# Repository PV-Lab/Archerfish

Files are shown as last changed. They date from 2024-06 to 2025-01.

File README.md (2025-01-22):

# \#Archerfish

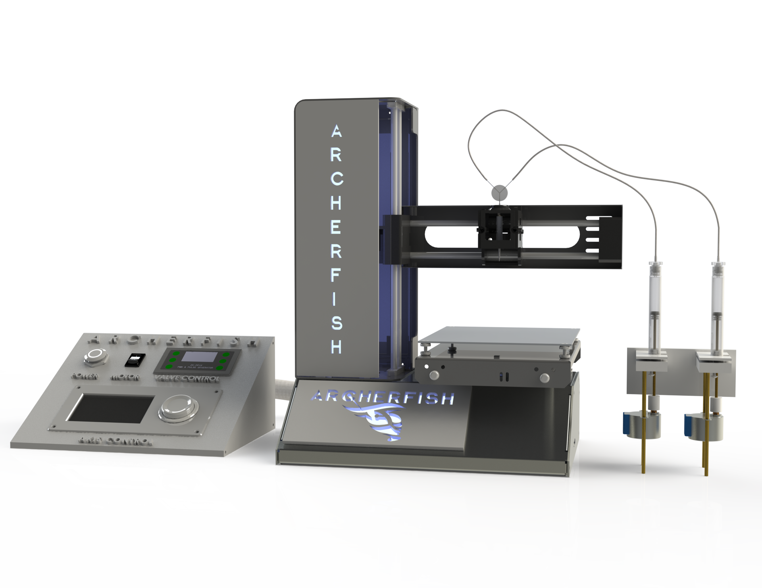
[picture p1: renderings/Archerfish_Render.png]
Archerfish


**Project Name:** \#Archerfish

**Project Lead:** Aleks Siemenn \<<asiemenn@mit.edu>\>

**Collaborators:** Jim Serdy, Basita Das, Eunice Aissi, Tonio Buonassisi

**Abstract**: The principle of "build fast, fail faster" has significantly shortened the timeline from ideation to final product in mechanical engineering, paralleling the rise of 3D printing technology and rapid prototyping. In contrast, material science has yet to achieve similar advancements in rapid learning cycles, hindered by the predominantly manual nature of its experimental procedures. For example, to test a material, it is conventionally synthesized at the same fidelity as industry standards, such as using manual spin coating, rather than being treated as a "rapid prototype." Implementing rapid prototyping principles into parts of these experimental procedures can help to shorten the timeline of the materials development pipeline, just as it does for mechanical design. Here, we introduce the design of Archerfish, a low-cost and high-throughput combinatorial mixing and deposition platform to accelerate the screening of material compounds. With this high-throughput combinatorial printing (HTCP) design, we demonstrate combinatorial mixing and printing throughputs of 250 unique compounds per minute. Furthermore, we validate the formation of combinatorial material gradients using hyperspectral image analysis. The proposed low-cost HTCP design expands accessibility to rapid materials screening technology, enabling scientists to make faster experimentally-informed decisions for the development of new materials. 

## Explanation of code within GitHub Repo:
### [1] Archerfish BOM.xlxs
Detailed Bill of Materials for the Archerfish System. 

### [2] /Code/Microcontroller Syringe Pump Code/Microcontroller-Syringe-Pump-Code.ino
Simple Arduino Mega gradient printing code for two 28BYJ-48 5V Stepper Motors with ULN2003 Drivers. This code drives both syringes in the archerfish system to create a gradient of droplets. Package version AccelStepper >= 1.64 and Arudino IDE >= 2.2.1 were used to develop this code.

### [3] /Code/Printer G-code/Raster Pattern.gcode
G-code for a Monoprice MP Select Mini 3D Printer to raster the gradient printed by the Archerfish system on a 100mm x 100mm polyester sheet. Marlin-flavor G-code is used to develop this code.

### [4] /Code/Script to Update G-code/Update_gcode.ipynb
Python notebook script to update an existing g-code file to the dimensions of any 3D printer bed size.

### [5] /CAD/Full Archerfish System Assembly.zip
Detailed CAD Model of the Archerfish System. Open-access CAD model of the complete Archerfish assembly can also be found on [GrabCAD](https://grabcad.com/library/archerfish-1). Included in this folder are the Solidworks files and 3D-printable STL files for all custom components.

### [6] /CAD/Droplet Generator and Junction
Contains all Solidworks part files and 3D-printable STL files to reproduce the droplet generation and junction assembly.

### [7] /CAD/Syringe Pump
Contains all Solidworks part files and 3D-printable STL files to reproduce the syringe pump holder assembly.

### [8] /data
The folder contains the paper's relevant hyperspectral, EDS, and profilometry data.

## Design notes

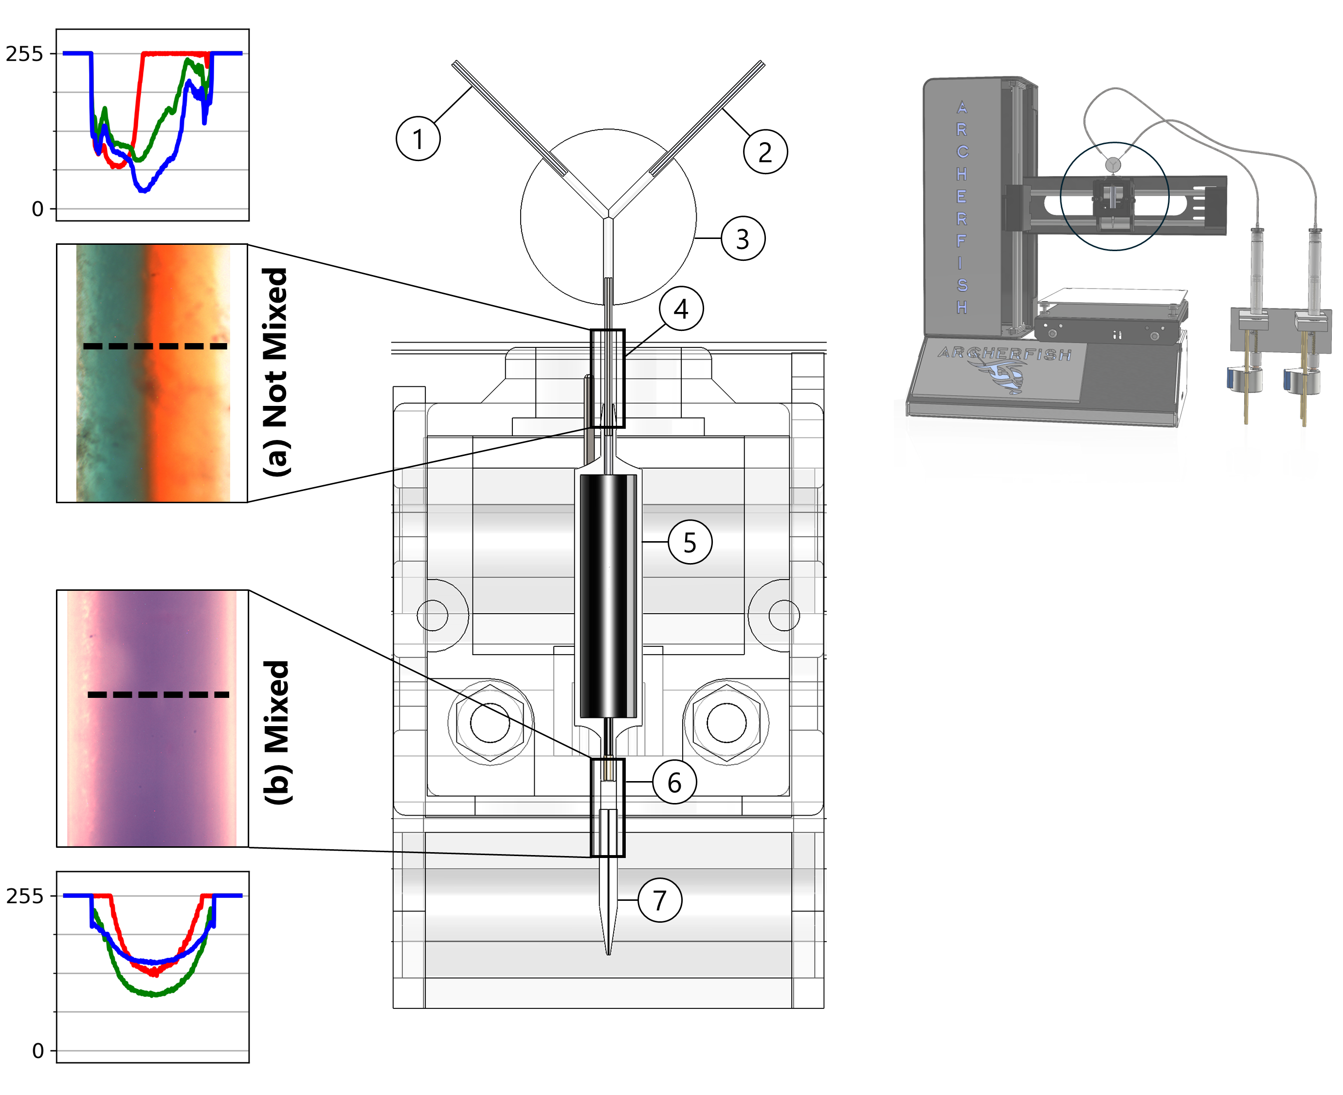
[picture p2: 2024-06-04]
renderings/Junction_nozzle_mixing_R1.png

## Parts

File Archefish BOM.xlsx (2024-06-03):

Summary Table
General Description | Cost
Lee Valve | $183.58
Mono Price Printer | $175.99
Nozzle | $50.00
Arduino Mega | $48.90
Fittings, Tubing, and Pumps | $23.39
PWM Driver | $10.57
Buttons & Switch | $8.82
Motors | $5.90
Total | $507.15
Sub-Assembly refers to the labels in Archerfish_render_complete_R2.png
Sub-Assembly | Image in Github Repo | Label in Figure | Item Name | Description | Vendor | Part Number | Qty | Cost/Item | Cost/Item | Link to Where to Purchase
1 | Archerfish_UI_Box.png | 1 | Screen and Control | Axis Controls From Monoprice 3D Printer | Mono Price
 |  | 2 | Power | Power Button | Digikey | SW-PB7-1Z-A-LRRG-H-3-G2A | 1 | $7.56 | $7.56 | https://www.digikey.com/en/products/detail/adam-tech/SW-PB7-1Z-A-LRRG-H-3-G2A/15284462?gad_source=1
 |  | 3 | UI Box | User Interface Box (PLA) | 3D printed |  | 1 | $0.00 | $0.00 | CAD File:
 |  | 4 | Switch | Motor Switch | Digikey | RF1-1A-DC-2-R-1 | 1 | $1.26 | $1.26 | https://www.digikey.com/en/products/detail/triad-components-group,-inc/RF1-1A-DC-2-R-1/11492837?gad_source=1
 |  | 5 | PWM Driver | ZK-PP2K 24V High Power PWM Driver | Amazon |  | 1 | $10.57 | $10.57 | https://www.amazon.com/ZK-PP2K-dimming-regulating-frequency-adjustable/dp/B0C7H1QFR8
2 | Archerfish_render_complete_R2.png | 2 | 3D Printer | Monoprice MP Select Mini 3D Printer (discontinued) | Mono Price |  | 1 | $175.99 | $175.99 | https://www.amazon.com/Monoprice-Select-Mini-Printer-Assembled/dp/B073ZLSMFT
3 | Junction_nozzle_mixing_R2.png | 1 & 2 | Metal Inlets | 0.55 mm ID x 0.65 mm OD x 25 mm, 304 stainless steel | McMaster-Carr | 5560K63 | 3 | $0.65 | $1.96 | https://www.mcmaster.com/5560K63-5560K332/
 |  | 3 | Junction | Fluid Junction. From 0.25" thick polyoxymethylene (POM/Acetal) disk with three 0.6 mm holes drilled 90 degrees apart | McMaster-Carr | 8497K311 | 1 | $6.26 | $6.26 | https://www.mcmaster.com/8497K311/
 |  | 4 & 6 |  | 0.5 mm ID x 2 mm OD silicone Tubing | Amazon |  | 2 | $0.03 | $0.06 | https://www.amazon.com/Hooshing-Silicone-Flexible-Winemaking-Transfer/dp/B0BJ1XCKGK?th=1
 |  | 5 | Valve | In-line Piezoelectric Valve | Lee Valves | INKA2424212H VHS Series P-P | 1 | $183.58 | $183.58 | https://www.theleeco.com/product/vhs-series-2-way-dispense-solenoid-valve/
 |  | 7 | Nozzle | 300 um Diameter Flow-focusing micro-nozzle outlet | Small Precision Tools | 1551-120-437P 200 (10-11D-20) | 1 | $50.00 | $50.00 | https://www.smallprecisiontools.com/en/homepage/?oid=55&lang=en
4 | Syringe_pump_construction_R2.png | 1 | Lines | Fluid Lines 1 mm ID and 2 mm OD PTFE [3 ft] | McMaster-Carr | 7130N273 | 2 | $4.38 | $8.76 | https://www.mcmaster.com/7130N273/
 |  | 2 | Luer lock | Barbed luer lock (1.5 mm, polypropylene (PP)) | McMaster-Carr | 51525K291 | 2 | $0.62 | $1.24 | https://www.mcmaster.com/51525K291/
 |  | 3 | Syringe | Syringe holding volume for precursor solutions (3 mL with luer lock connection, PP) | McMaster-Carr | 7510A42 | 2 | $1.22 | $2.44 | https://www.mcmaster.com/7510A42/
 |  | 4 | Plunger | Syringe plunger cap (silicone) | Sub-Unit of a Syringe. Made in-house. |  | 2 |  | $0.00
 |  | 5 | Shaft | Threaded plunger shaft (#4-40 threads × 75 mm length, 18-8 stainless steel), | McMaster-Carr | 95412A410 | 2 | $1.14 | $2.28 | https://www.mcmaster.com/95412A410/
 |  | 6 | Plunger Coupling | Plunger shaft coupling to convert angular to linear velocity (#4-40 threads, polyoxymethylene (POM), 3/8" Rod 5/16" long) | McMaster-Carr | 8497K171 | 1 | $0.03 | $0.03 | https://www.mcmaster.com/8497K171/
 |  | 7 | Rails | Stepper motor rails (3 mm diameter × 90 mm length, aluminum) | McMaster-Carr | 8974K19 | 1 | $0.31 | $0.31 | https://www.mcmaster.com/8974K19/
 |  | 8 | Motor Coupling | Motor shaft coupling with lead screw (POM, 3/8" Rod 1/2" Long ) | McMaster-Carr | 8497K171 | 1 | $0.05 | $0.05 | https://www.mcmaster.com/8497K171/
 |  | 9 | Motors | 28BYJ-48 5V Stepper Motors + ULN2003 Driver | Amazon |  | 2 | $2.95 | $5.90 | https://www.amazon.com/Stepper-28BYJ-48-ULN2003-Arduino-Electric/dp/B07V5V2FZX?hvadid=693270340266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
 |  | Not Depicted | Mega | Arduino Mega | Amazon |  | 1 | $48.90 | $48.90 | https://www.amazon.com/ARDUINO-MEGA-2560-REV3-A000067/dp/B0046AMGW0?hvadid=693392565994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
 |  |  |  |  |  |  | Total |  | $507.15

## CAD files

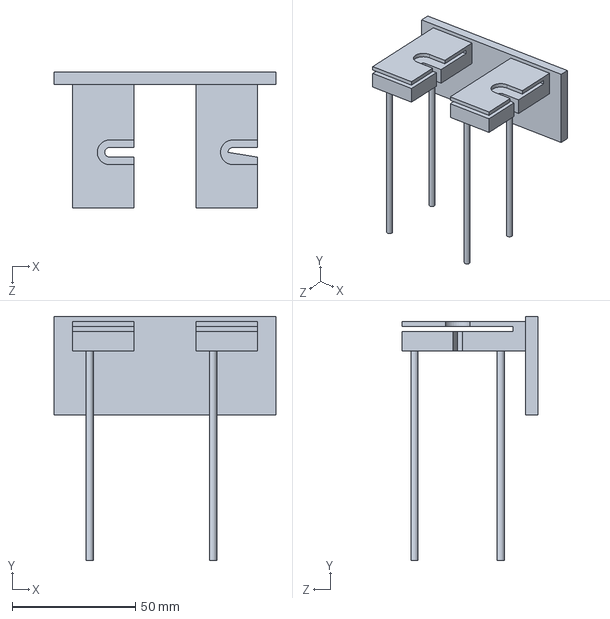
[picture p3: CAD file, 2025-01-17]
CAD/Syringe Pump/Solidworks Files/Full Syringe Holder.SLDPRT
90.0 x 99.0 x 55.0 mm

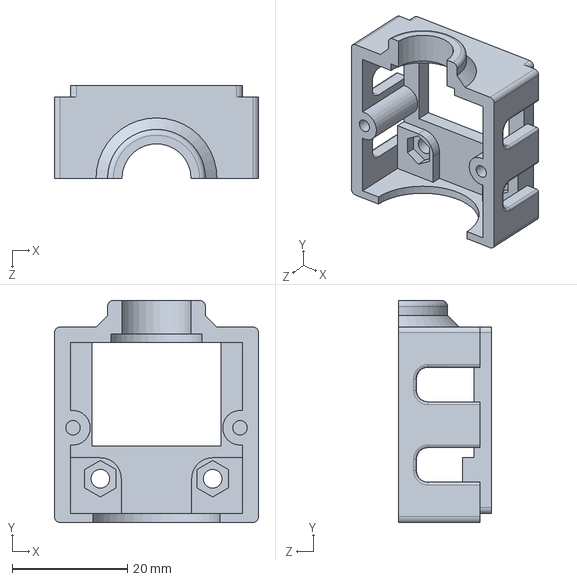
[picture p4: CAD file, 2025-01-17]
CAD/Droplet Generator and Junction/Solidworks Files/Droplet Generator Back Cover.SLDPRT
35.5 x 38.5 x 16.1 mm

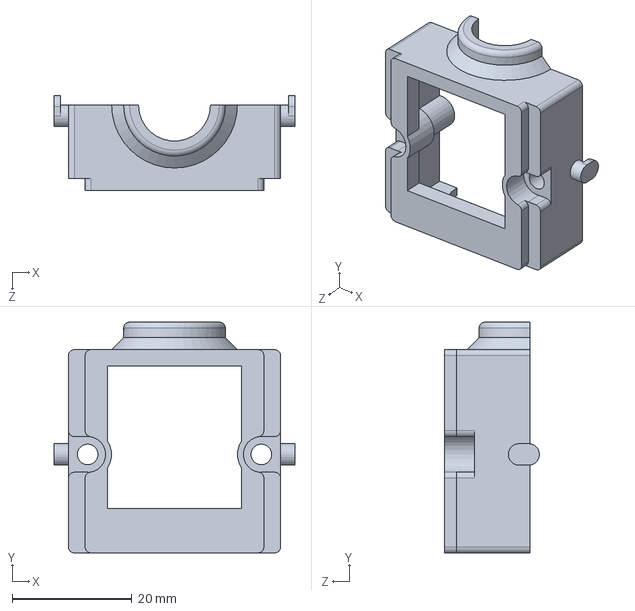
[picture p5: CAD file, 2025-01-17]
CAD/Droplet Generator and Junction/Solidworks Files/Droplet Generator Front Cover.SLDPRT
40.2 x 38.5 x 15.9 mm

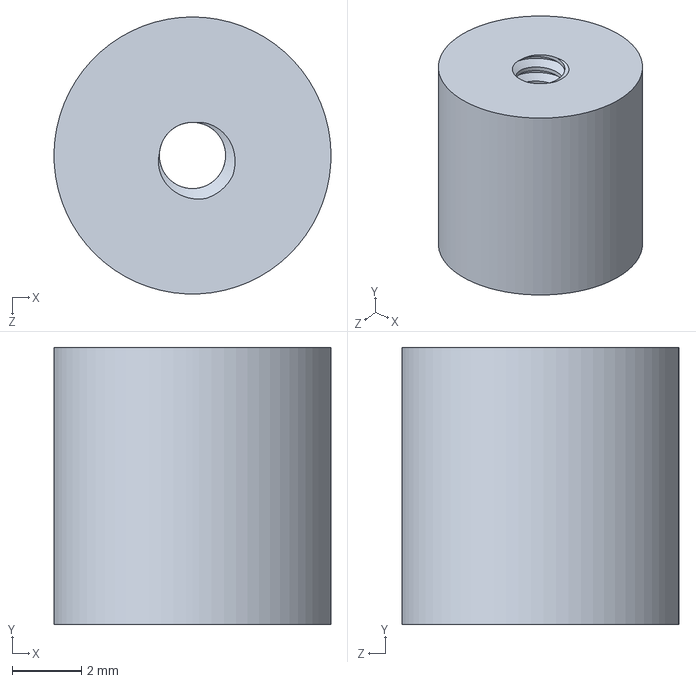
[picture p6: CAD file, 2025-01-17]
CAD/Syringe Pump/Solidworks Files/Syringe Pump Drive-to-Syringe Coupling.SLDPRT
8.00 x 8.00 x 8.00 mm

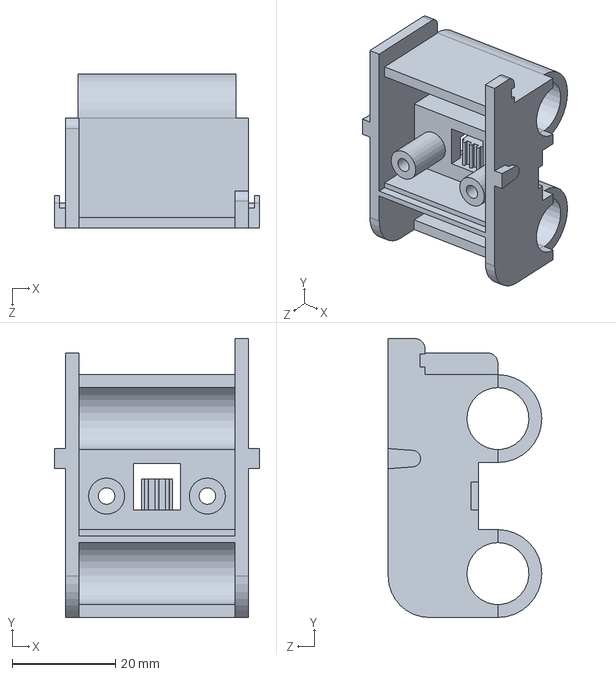
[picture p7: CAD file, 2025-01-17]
CAD/Droplet Generator and Junction/Solidworks Files/Droplet Generator Mount.SLDPRT
39.7 x 54.0 x 29.8 mm

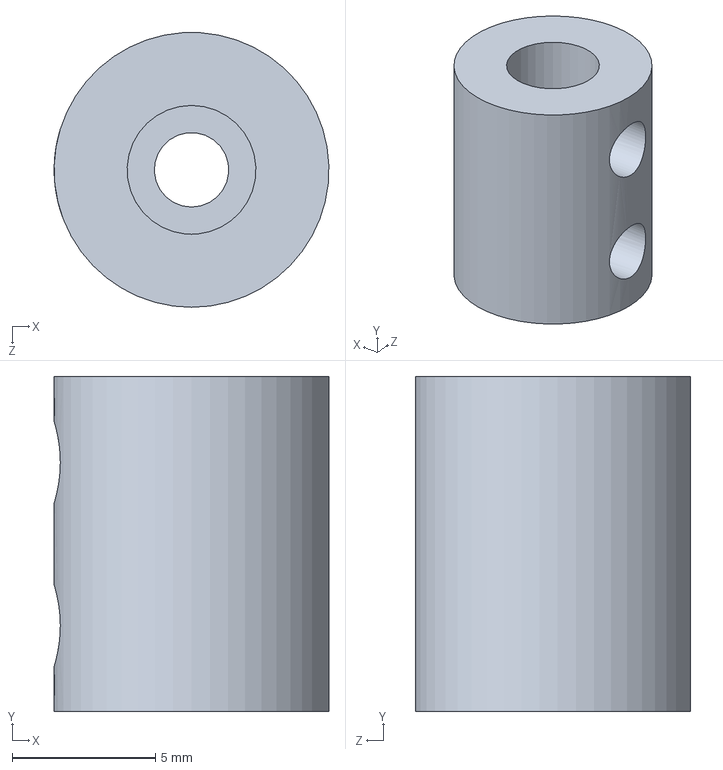
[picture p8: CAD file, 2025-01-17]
CAD/Syringe Pump/Solidworks Files/Syringe Pump Drive-to-Motor Coupling.SLDPRT
9.60 x 11.7 x 9.59 mm

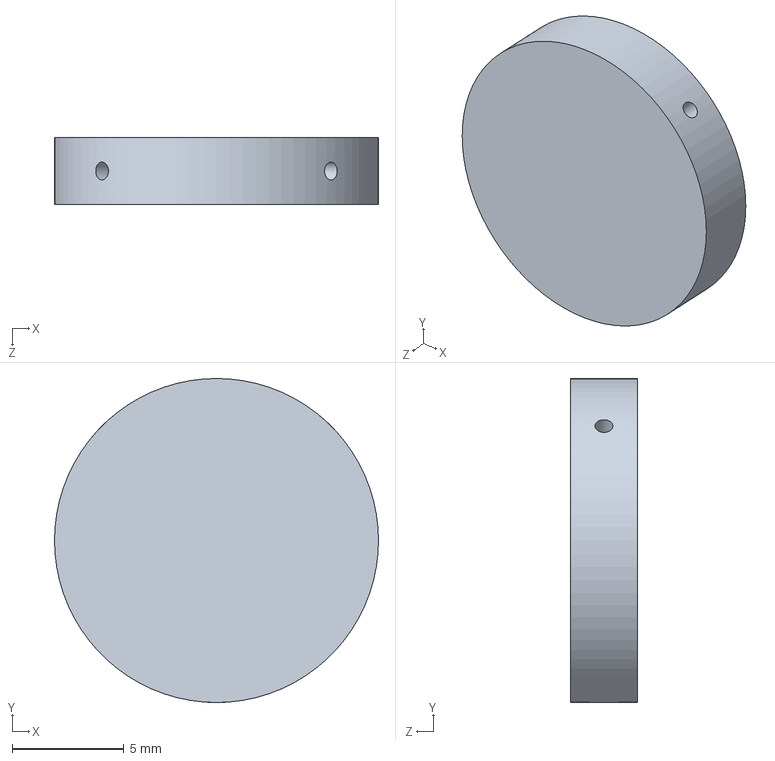
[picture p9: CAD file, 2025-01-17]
CAD/Droplet Generator and Junction/Solidworks Files/Junction Mixer 45 Degrees.SLDPRT
14.5 x 14.5 x 3.00 mm

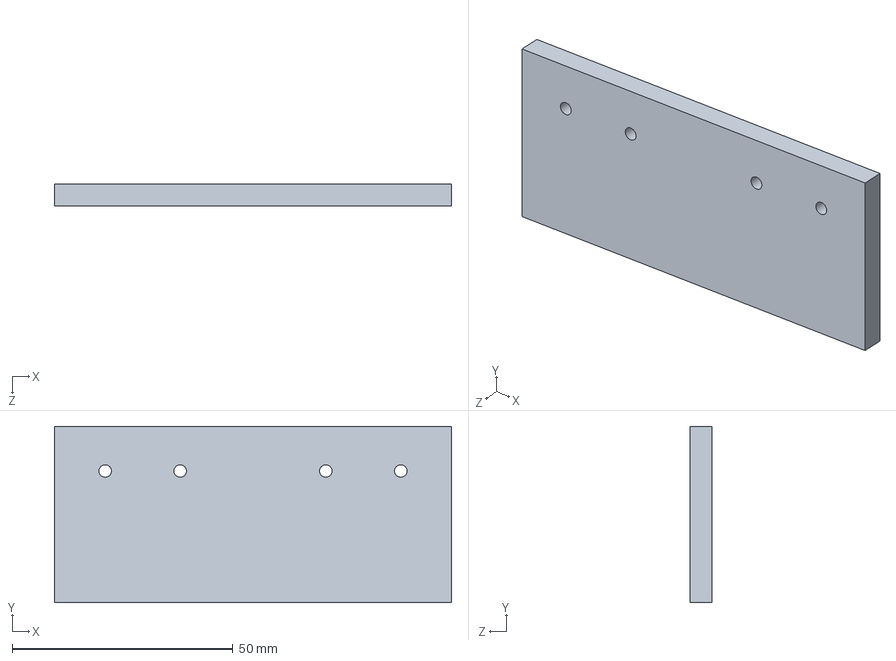
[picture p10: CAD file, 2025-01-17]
CAD/Syringe Pump/Solidworks Files/Syringe Holder Back Plate.SLDPRT
90.0 x 40.0 x 5.00 mm

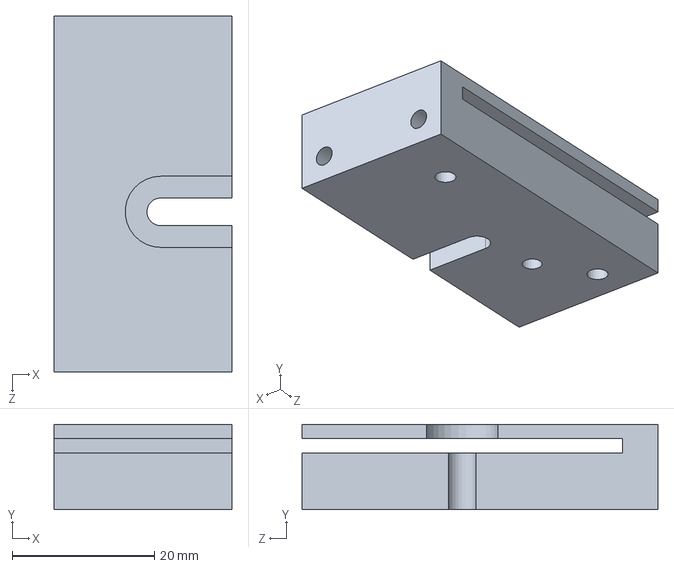
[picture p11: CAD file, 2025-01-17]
CAD/Syringe Pump/Solidworks Files/Syringe Mount.SLDPRT
25.0 x 12.0 x 50.0 mm

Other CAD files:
CAD/Droplet Generator and Junction/3D Printable Files/Droplet Generator Back Cover.STL
CAD/Droplet Generator and Junction/3D Printable Files/Droplet Generator Front Cover.STL
CAD/Droplet Generator and Junction/3D Printable Files/Droplet Generator Mount.STL
CAD/Droplet Generator and Junction/3D Printable Files/Junction Mixer 45 Degrees.STL
CAD/Syringe Pump/3D Printable Files/Syringe Holder Back Plate.STL
CAD/Syringe Pump/3D Printable Files/Syringe Mount.STL
CAD/Syringe Pump/3D Printable Files/Syringe Pump Drive-to-Motor Coupling.STL
CAD/Syringe Pump/3D Printable Files/Syringe Pump Drive-to-Syringe Coupling.STL

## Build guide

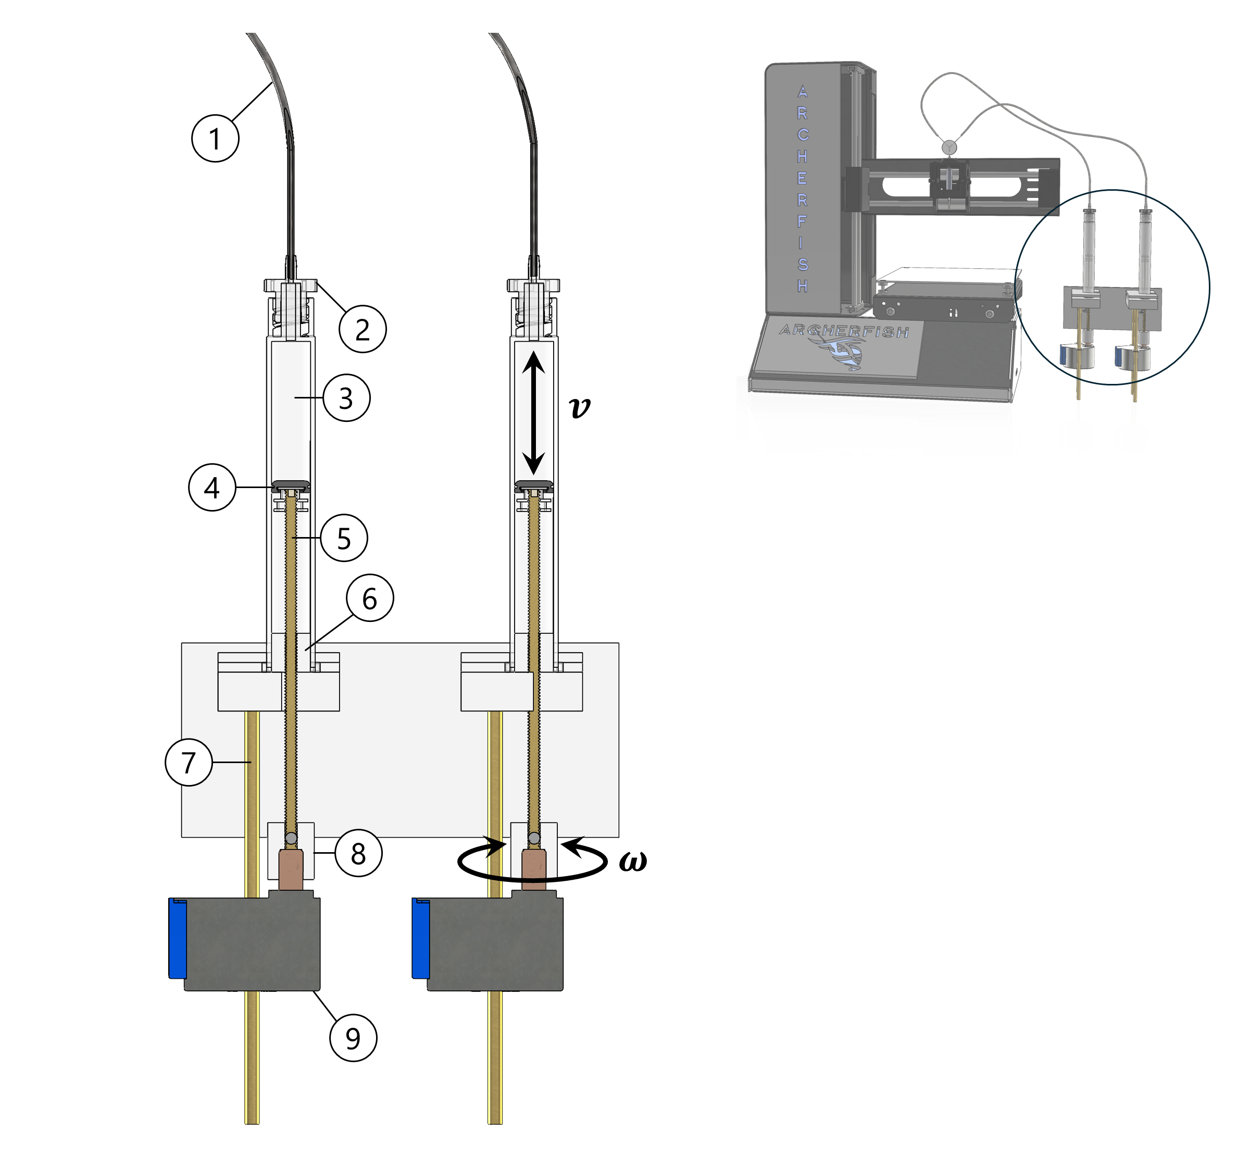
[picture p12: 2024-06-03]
renderings/Syringe_pump_construction_R2.png

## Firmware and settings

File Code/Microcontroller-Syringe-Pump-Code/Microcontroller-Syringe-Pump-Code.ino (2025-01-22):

// Author: Aleks Siemenn <asiemenn@mit.edu>
// Keep file up-to-date: https://github.com/PV-Lab/Archerfish
// =============== VARIABLE SETUP  =============== //
int maxStepSpeed = 400.0; // max stepSpeed = 800 before failure/unreliable
int stepAccel = 1000.0; // don't really need to change this acceleration value
int stepTime =10; // seconds. don't exceed 30 seconds or it will run forever
                   // motors run for stepTime*(number of motors)
int stepDirection = -1; // -1 for CW (plunger goes down) and 1 for CCW (plunger goes up) [motor pin facing down]
char firstMotor = 'A'; // 'A' => first, motor A runs for stepTime then turns off and motor B runs for stepTime
                       // 'B' => first, motor B runs for stepTime then turns off and motor A runs for stepTime

int increment = 2;
// Stepper A pins
int a1 = 13;
int a2 = 12;
int a3 = 11;
int a4 = 10;
// Stepper B pins
int b1 = 5; 
int b2 = 4;
int b3 = 3;
int b4 = 2;
unsigned long begin_time;
unsigned long begin_time2;
//
// ===== //
// Notes
// - Set voltage for Arduino and all stepper motors to ~5V
// ============================================== //
// ============================================== //
//
//
// =========== CONTROLLER CODE BELOW =========== //
#include <AccelStepper.h> // Include the AccelStepper library for controlling stepper motors

#define FULLSTEP 4 
// The 28BYJ-48 stepper can be driven in FULLSTEP mode using 4 steps.
// (There are also other modes like HALFSTEP, but here we define FULLSTEP = 4.)

// Create two stepper motor objects using the AccelStepper library.
// The constructor arguments are (interface, pin1, pin2, pin3, pin4).
// 'interface' is set to FULLSTEP to match the driver/motor mode.
AccelStepper stepperA(FULLSTEP, a1, a3, a2, a4); 
AccelStepper stepperB(FULLSTEP, b1, b3, b2, b4);

// Declare global/local variables for usage in setup() and loop().
int i;               // A variable used as a dynamic speed control index.
int buffer_time = 1000;  // A delay threshold in milliseconds, used to delay stepping logic.

void setup() {
    Serial.begin(115200); // Start serial communication at 115200 baud for debugging.

    // -------------------- Stepper A (stepperA) Settings --------------------
    stepperA.setMaxSpeed(maxStepSpeed);    
    // Set the maximum stepping speed (steps per second) for stepperA.
    // maxStepSpeed is presumably defined elsewhere, e.g. 300 steps/s.

    stepperA.setAcceleration(stepAccel);
    // Set the acceleration (in steps per second^2) for stepperA.
    // stepAccel is presumably defined elsewhere, e.g. 1000.0.

    stepperA.moveTo(stepDirection * 1000000);
    // Command stepperA to move a large number of steps in the specified direction.
    // This effectively makes it run 'indefinitely' until we stop or change conditions.

    // -------------------- Stepper B (stepperB) Settings --------------------
    stepperB.setMaxSpeed(maxStepSpeed);
    // Set the maximum stepping speed for stepperB.

    stepperB.setAcceleration(stepAccel);
    // Set the acceleration for stepperB.

    stepperB.moveTo(stepDirection * 1000000);
    // Same idea as with stepperA: move a large number of steps so it keeps running.

    begin_time = millis();   // Initialize a timestamp variable (declared elsewhere).
    begin_time2 = millis();  // Another timestamp for different logic in loop.
    i = 0;                   // Initialize the speed-incrementing variable to 0.
}

void loop() {
    // If less time than buffer_time has passed since begin_time2,
    // set stepperA speed to 0 and stepperB speed to negative maxStepSpeed.
    // This creates an initial delay or 'buffer' condition for stepperA,
    // while stepperB moves in the negative direction (for demonstration or positioning).
    if (millis() - begin_time2 < buffer_time) {
        stepperA.setSpeed(0); 
        // Stepper A does not move during the buffer time.
        stepperB.setSpeed(-maxStepSpeed);
        // Stepper B moves at maximum speed in the negative direction.
    }

    // Once buffer_time has elapsed, incrementally change speeds of both motors
    // until stepperA reaches maxStepSpeed and stepperB's speed goes to 0.
    if ((i < maxStepSpeed) && ((millis() - begin_time2) >= buffer_time)) {

        // Only update speeds every so often, based on the begin_time interval.
        if ((millis() - begin_time) > (maxStepSpeed / 2)) {
            float Aspeed = (float)i; // Cast i to float for clarity.
            stepperA.setSpeed(stepDirection * Aspeed);
            // Gradually increase stepperA's speed from 0 to maxStepSpeed in 'stepDirection'.
            Serial.print("A speed: ");
            Serial.println(Aspeed);

            float Bspeed = (float)(maxStepSpeed - i);
            stepperB.setSpeed(stepDirection * Bspeed);
            // Decrease stepperB's speed from maxStepSpeed down to 0 in 'stepDirection'.
            Serial.print("B speed: ");
            Serial.println(Bspeed);

            // Increase i by some defined increment. This controls how quickly
            // stepperA speeds up and stepperB slows down.
            i += increment;

            // Update the time checkpoint so we don't update too frequently.
            begin_time = millis();
        }

        // Once i reaches or exceeds maxStepSpeed, stepperA is set to run
        // at -maxStepSpeed (reversing direction), and stepperB is stopped (speed 0).
        if (i >= maxStepSpeed) {
            stepperA.setSpeed(-maxStepSpeed);
            stepperB.setSpeed(0);
        }
    }

    // The runSpeed() function advances the motor at the most recently set speed.
    // This must be called frequently (ideally each loop) to keep the motor stepping.
    stepperA.runSpeed();
    stepperB.runSpeed();
}

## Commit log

2024-06-04 Upload Archerfish complete CAD and renderings
2024-06-04 Upload Arduino code
2024-08-04 Upload data files
    [EDS_CsBiBrI.csv, Hyperspectral_Blue_to_Yellow_Dyes.csv, Hyperspectral_MAFAPbI_with_background.csv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]
2025-01-17 Upload user-friendly CAD and 3D printable files
    [Droplet Generator Back Cover.SLDPRT, Droplet Generator Back Cover.STL, Droplet Generator Front Cover.SLDPRT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]
2025-01-18 Upload Arduino gradient code for 2 syringe pumps
2025-01-22 Upload commented Arduino code
2025-01-22 Upload script to modify g-code to any 3D printer bed size
